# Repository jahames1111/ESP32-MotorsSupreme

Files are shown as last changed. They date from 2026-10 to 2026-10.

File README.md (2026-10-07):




# ESP32-MotorsSupreme

A huge motor driver board based on ESP32 featuring capacitors and motor/servo output pins everywhere.

## Features

- 8 DRV8833 motor drivers for 16 2 directional PWM motor outputs
- 2 PCA9685 chips for servo outputs and one pin of the DRV channels (the other is the ESP pin)
- 16 ESP32-S2 WROVER pins for DRV direction control
- Built for testing nonworking motors and servos



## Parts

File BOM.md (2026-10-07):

# ESP32-Motors Supreme — bill of materials

<!-- Generated by Half Life from project cmuv750pn0ea501smdojupz3y. Edits here are overwritten on the next sync. -->
<!-- Generated: 2026-10-07T14:09:51.534Z -->

> [!NOTE]
> This parts list is mirrored from [Half Life](https://halflife.hackclub.com). Editing it here will not change the platform's copy, and the next sync overwrites this file.

| Week | Tier | Parts funding |
| --- | --- | --- |
| Week 1 | Tier 2 | $65.00 |

| Part | What it's for | Qty | Unit | Total | Vendor |
| --- | --- | --- | --- | --- | --- |
| [JLCPCB Printed Board + Enclosure case](https://cart.jlcpcb.com/shopcart/cartEdit/?id=c26c80bae765480d8adc16bf88983d1a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) | Main PCB + case | 1 | $13.00 | $13.00 | [JLCPCB](https://cart.jlcpcb.com/shopcart/cartEdit/?id=c26c80bae765480d8adc16bf88983d1a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) |
| [LCSC Parts](https://www.lcsc.com/cart) | PCB Assembly | 1 | $45.00 | $45.00 | [LCSC](https://www.lcsc.com/cart) |
| **Parts subtotal** | — | — | — | **$58.00** | — |
| **Tax & shipping** | — | — | — | **$0.00** | — |
| **Total** | — | — | — | **$58.00** | — |

$7.00 left of the tier's funding.

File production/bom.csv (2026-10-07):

Designator | Footprint | Quantity | Value | LCSC Part #
C1 | CP_Radial_D8.0mm_P3.50mm | 1 | 470uf
C10, C12, C13, C14, C15, C16, C17, C18, C19, C3, C4, C5, C6, C7, C8, C9 | 1206 | 16 | 2.2uf
C11 | 1206 | 1 | 0.1uf
C2 | 1206 | 1 | 470uf
D1, D2 | D_SMA | 2 | D_Schottky
J1 | SolderWire-1sqmm_1x01_D1.4mm_OD3.9mm | 1 | BAT-
J10, J11, J12, J13, J14, J15, J16, J17, J18, J3, J4, J5, J6, J7, J8, J9 | PinHeader_1x02_P2.54mm_Vertical | 16 | Conn_01x02_Pin
J19, J20, J21 | PinHeader_1x16_P2.54mm_Vertical | 3 | Conn_01x16_Pin
J2 | SolderWire-1sqmm_1x01_D1.4mm_OD3.9mm | 1 | BAT+
J22 | USB_C_Receptacle_HRO_TYPE-C-31-M-12 | 1 | USB_C_Receptacle_USB2.0_16P
R1, R2 | 1206 | 2 | 4.7k
R3, R4, R5, R6 | 1206 | 4 | 5.1k
SW1, SW2 | SW_PUSH_6mm | 2 | SW_Push
U1 | ESP32-S2-WROVER | 1 | ESP32-S2-WROVER
U10, U11, U12, U13, U6, U7, U8, U9 | HTSSOP-16-1EP_4.4x5mm_P0.65mm_EP3.4x5mm_Mask2.46x2.31mm_ThermalVias | 8 | DRV8833PWP
U2, U5 | TSSOP-28_4.4x9.7mm_P0.65mm | 2 | PCA9685PW
U3 | SOT-23-5 | 1 | MIC5219-3.3YM5

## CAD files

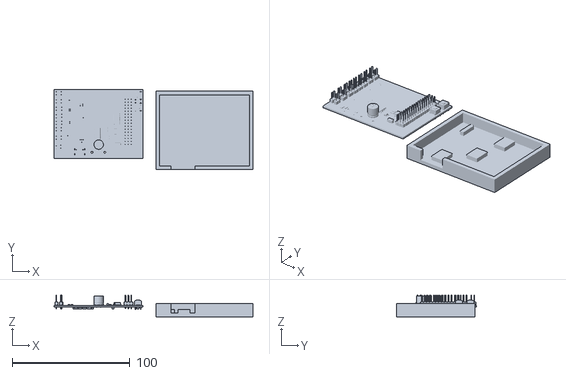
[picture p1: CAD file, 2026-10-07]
board and holder.stl
169.2 x 68.3 x 18.4

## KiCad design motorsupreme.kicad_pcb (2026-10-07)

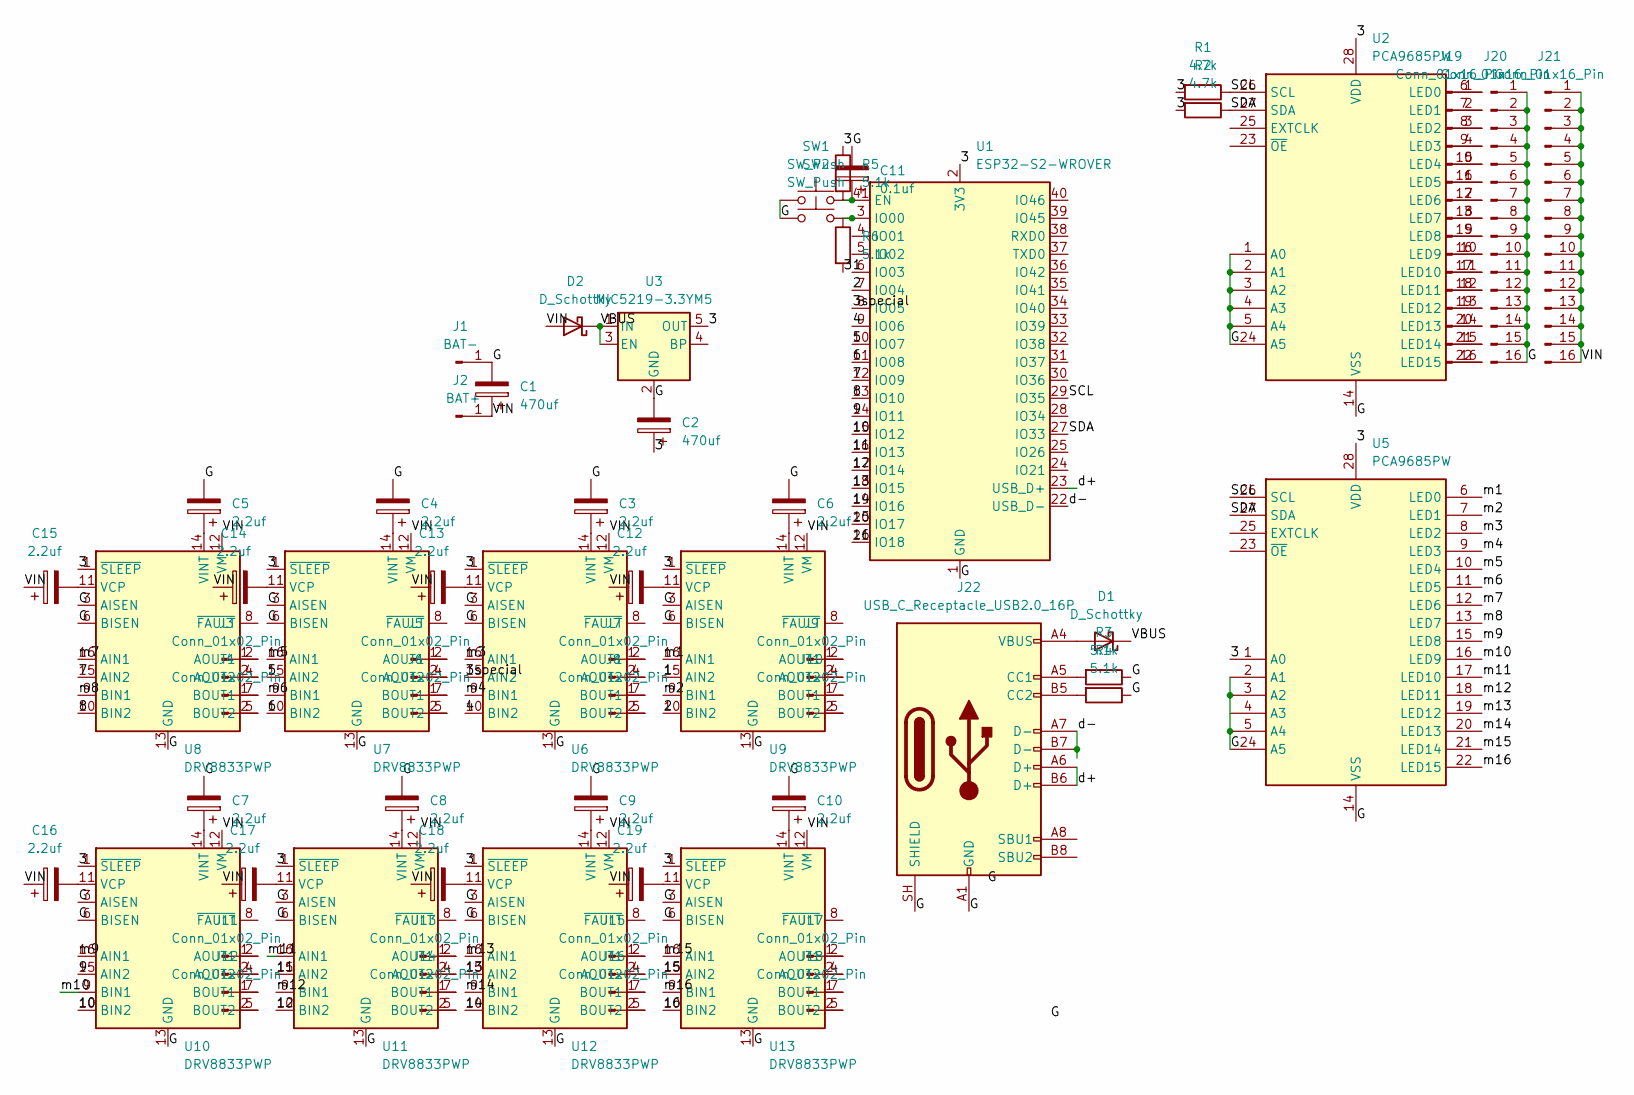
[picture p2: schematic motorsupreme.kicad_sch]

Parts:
C1: 470uf; CP_Radial_D8.0mm_P3.50mm
C2: 470uf; C_1206_3216Metric
C3, C4, C5, C6, C7, C8, C9, C10, C12, C13, C14, C15, C16, C17, C18, C19: 2.2uf; C_1206_3216Metric
C11: 0.1uf; C_1206_3216Metric
D1, D2: D_Schottky; D_SMA
J1: BAT-; SolderWire-1sqmm_1x01_D1.4mm_OD3.9mm
J2: BAT+; SolderWire-1sqmm_1x01_D1.4mm_OD3.9mm
J3, J4, J5, J6, J7, J8, J9, J10, J11, J12, J13, J14, J15, J16, J17, J18: Conn_01x02_Pin; PinHeader_1x02_P2.54mm_Vertical
J19, J20, J21: Conn_01x16_Pin; PinHeader_1x16_P2.54mm_Vertical
J22: USB_C_Receptacle_USB2.0_16P; USB_C_Receptacle_HRO_TYPE-C-31-M-12
R1, R2: 4.7k; R_1206_3216Metric
R3, R4, R5, R6: 5.1k; R_1206_3216Metric
SW1, SW2: SW_Push; SW_PUSH_6mm
U1: ESP32-S2-WROVER
U2, U5: PCA9685PW; TSSOP-28_4.4x9.7mm_P0.65mm
U3: MIC5219-3.3YM5; SOT-23-5
U6, U7, U8, U9, U10, U11, U12, U13: DRV8833PWP; HTSSOP-16-1EP_4.4x5mm_P0.65mm_EP3.4x5mm_Mask2.46x2.31mm_The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

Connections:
/1: U1.6 (IO03), U9.15 (AIN2)
/2: U1.7 (IO04), U9.10 (BIN2)
/3: C2.1, R1.2, R2.2, R5.1, R6.2, U1.2 (3V3), U2.28 (VDD), U3.5 (OUT), U5.1 (A0), U5.28 (VDD), U6.1 (~SLEEP), U7.1 (~SLEEP), U8.1 (~SLEEP), U9.1 (~SLEEP), U10.1 (~SLEEP), U11.1 (~SLEEP), U12.1 (~SLEEP), U13.1 (~SLEEP)
/3special: U1.8 (IO05), U6.15 (AIN2)
/4: U1.9 (IO06), U6.10 (BIN2)
/5: U1.10 (IO07), U7.15 (AIN2)
/6: U1.11 (IO08), U7.10 (BIN2)
/7: U1.12 (IO09), U8.15 (AIN2)
/8: U1.13 (IO10), U8.10 (BIN2)
/9: U1.14 (IO11), U10.15 (AIN2)
/10: U1.15 (IO12), U10.10 (BIN2)
/11: U1.16 (IO13), U11.15 (AIN2)
/12: U1.17 (IO14), U11.10 (BIN2)
/13: U1.18 (IO15), U12.15 (AIN2)
/14: U1.19 (IO16), U12.10 (BIN2)
/15: U1.20 (IO17), U13.15 (AIN2)
/16: U1.21 (IO18), U13.10 (BIN2)
/G: C1.2, C2.2, C3.2, C4.2, C5.2, C6.2, C7.2, C8.2, C9.2, C10.2, C11.2, J1.1 (Pin_1_1), J20.1, J20.2, J20.3, J20.4, J20.5, J20.6, J20.7, J20.8, J20.9, J20.10, J20.11, J20.12, J20.13, J20.14, J20.15, J20.16, J22.A1 (GND), J22.A12 (GND), J22.B1 (GND), J22.B12 (GND), J22.SH (SHIELD), R3.1, R4.1, SW1.1, SW2.1, U1.1 (GND), U1.26 (GND), U1.42 (GND), U1.43 (GND), U2.1 (A0), U2.2 (A1), U2.3 (A2), U2.4 (A3), U2.5 (A4), U2.14 (VSS), U2.24 (A5), U3.2 (GND), U5.2 (A1), U5.3 (A2), U5.5 (A4), U5.14 (VSS), U5.24 (A5), U6.3 (AISEN), U6.6 (BISEN), U6.13 (GND), U6.17 (GND), U7.3 (AISEN), U7.6 (BISEN), U7.13 (GND), U7.17 (GND), U8.3 (AISEN), U8.6 (BISEN), U8.13 (GND), U8.17 (GND), U9.3 (AISEN), U9.6 (BISEN), U9.13 (GND), U9.17 (GND), U10.3 (AISEN), U10.6 (BISEN), U10.13 (GND), U10.17 (GND), U11.3 (AISEN), U11.6 (BISEN), U11.13 (GND), U11.17 (GND), U12.3 (AISEN), U12.6 (BISEN), U12.13 (GND), U12.17 (GND), U13.3 (AISEN), U13.6 (BISEN), U13.13 (GND), U13.17 (GND)
/SCL: R1.1, U1.29 (IO35), U2.26 (SCL), U5.26 (SCL)
/SDA: R2.1, U1.27 (IO33), U2.27 (SDA), U5.27 (SDA)
/VBUS: D1.1 (K), D2.1 (K), U3.1 (IN), U3.3 (EN)
/VIN: C1.1, C12.1, C13.1, C14.1, C15.1, C16.1, C17.1, C18.1, C19.1, D2.2 (A), J2.1 (Pin_1_1), J21.1, J21.2, J21.3, J21.4, J21.5, J21.6, J21.7, J21.8, J21.9, J21.10, J21.11, J21.12, J21.13, J21.14, J21.15, J21.16, U6.12 (VM), U7.12 (VM), U8.12 (VM), U9.12 (VM), U10.12 (VM), U11.12 (VM), U12.12 (VM), U13.12 (VM)
/d+: J22.A6 (D+), J22.B6 (D+), U1.23 (USB_D+)
/d-: J22.A7 (D-), J22.B7 (D-), U1.22 (USB_D-)
/m1: U5.6 (LED0), U9.16 (AIN1)
/m2: U5.7 (LED1), U9.9 (BIN1)
/m3: U5.8 (LED2), U6.16 (AIN1)
/m4: U5.9 (LED3), U6.9 (BIN1)
/m5: U5.10 (LED4), U7.16 (AIN1)
/m6: U5.11 (LED5), U7.9 (BIN1)
/m7: U5.12 (LED6), U8.16 (AIN1)
/m8: U5.13 (LED7), U8.9 (BIN1)
/m9: U5.15 (LED8), U10.16 (AIN1)
/m10: U5.16 (LED9), U10.9 (BIN1)
/m11: U5.17 (LED10), U11.16 (AIN1)
/m12: U5.18 (LED11), U11.9 (BIN1)
/m13: U5.19 (LED12), U12.16 (AIN1)
/m14: U5.20 (LED13), U12.9 (BIN1)
/m15: U5.21 (LED14), U13.16 (AIN1)
/m16: U5.22 (LED15), U13.9 (BIN1)
unnamed: D1.2 (A), J22.A4 (VBUS), J22.A9 (VBUS), J22.B4 (VBUS), J22.B9 (VBUS)
unnamed: J3.1, U8.2 (AOUT1)
unnamed: J3.2, U8.4 (AOUT2)
unnamed: J4.1, U8.7 (BOUT1)
unnamed: J4.2, U8.5 (BOUT2)
unnamed: J5.1, U7.2 (AOUT1)
unnamed: J5.2, U7.4 (AOUT2)
unnamed: J6.1, U7.7 (BOUT1)
unnamed: J6.2, U7.5 (BOUT2)
unnamed: J7.1, U6.2 (AOUT1)
unnamed: J7.2, U6.4 (AOUT2)
unnamed: J8.1, U6.7 (BOUT1)
unnamed: J8.2, U6.5 (BOUT2)
unnamed: J9.1, U9.2 (AOUT1)
unnamed: J9.2, U9.4 (AOUT2)
unnamed: J10.1, U9.7 (BOUT1)
unnamed: J10.2, U9.5 (BOUT2)
unnamed: J11.1, U10.2 (AOUT1)
unnamed: J11.2, U10.4 (AOUT2)
unnamed: J12.1, U10.7 (BOUT1)
unnamed: J12.2, U10.5 (BOUT2)
unnamed: J13.1, U11.2 (AOUT1)
unnamed: J13.2, U11.4 (AOUT2)
unnamed: J14.1, U11.7 (BOUT1)
unnamed: J14.2, U11.5 (BOUT2)
unnamed: J15.1, U12.2 (AOUT1)
unnamed: J15.2, U12.4 (AOUT2)
unnamed: J16.1, U12.7 (BOUT1)
unnamed: J16.2, U12.5 (BOUT2)
unnamed: J17.1, U13.2 (AOUT1)
unnamed: J17.2, U13.4 (AOUT2)
unnamed: J18.1, U13.7 (BOUT1)
unnamed: J18.2, U13.5 (BOUT2)
unnamed: J19.1, U2.6 (LED0)
unnamed: J19.2, U2.7 (LED1)
unnamed: J19.3, U2.8 (LED2)
unnamed: J19.4, U2.9 (LED3)
unnamed: J19.5, U2.10 (LED4)
unnamed: J19.6, U2.11 (LED5)
unnamed: J19.7, U2.12 (LED6)
unnamed: J19.8, U2.13 (LED7)
unnamed: J19.9, U2.15 (LED8)
unnamed: J19.10, U2.16 (LED9)
unnamed: J19.11, U2.17 (LED10)
unnamed: J19.12, U2.18 (LED11)
unnamed: J19.13, U2.19 (LED12)
unnamed: J19.14, U2.20 (LED13)
unnamed: J19.15, U2.21 (LED14)
unnamed: J19.16, U2.22 (LED15)
unnamed: J22.A5 (CC1), R3.2
unnamed: J22.B5 (CC2), R4.2
unnamed: C11.1, R5.2, SW1.2, U1.41 (EN)
unnamed: R6.1, SW2.2, U1.3 (IO00)
unnamed: C13.2, U6.11 (VCP)
unnamed: C3.1, U6.14 (VINT)
unnamed: C14.2, U7.11 (VCP)
unnamed: C4.1, U7.14 (VINT)
unnamed: C15.2, U8.11 (VCP)
unnamed: C5.1, U8.14 (VINT)
unnamed: C12.2, U9.11 (VCP)
unnamed: C6.1, U9.14 (VINT)
unnamed: C16.2, U10.11 (VCP)
unnamed: C7.1, U10.14 (VINT)
unnamed: C17.2, U11.11 (VCP)
unnamed: C8.1, U11.14 (VINT)
unnamed: C18.2, U12.11 (VCP)
unnamed: C9.1, U12.14 (VINT)
unnamed: C19.2, U13.11 (VCP)
unnamed: C10.1, U13.14 (VINT)

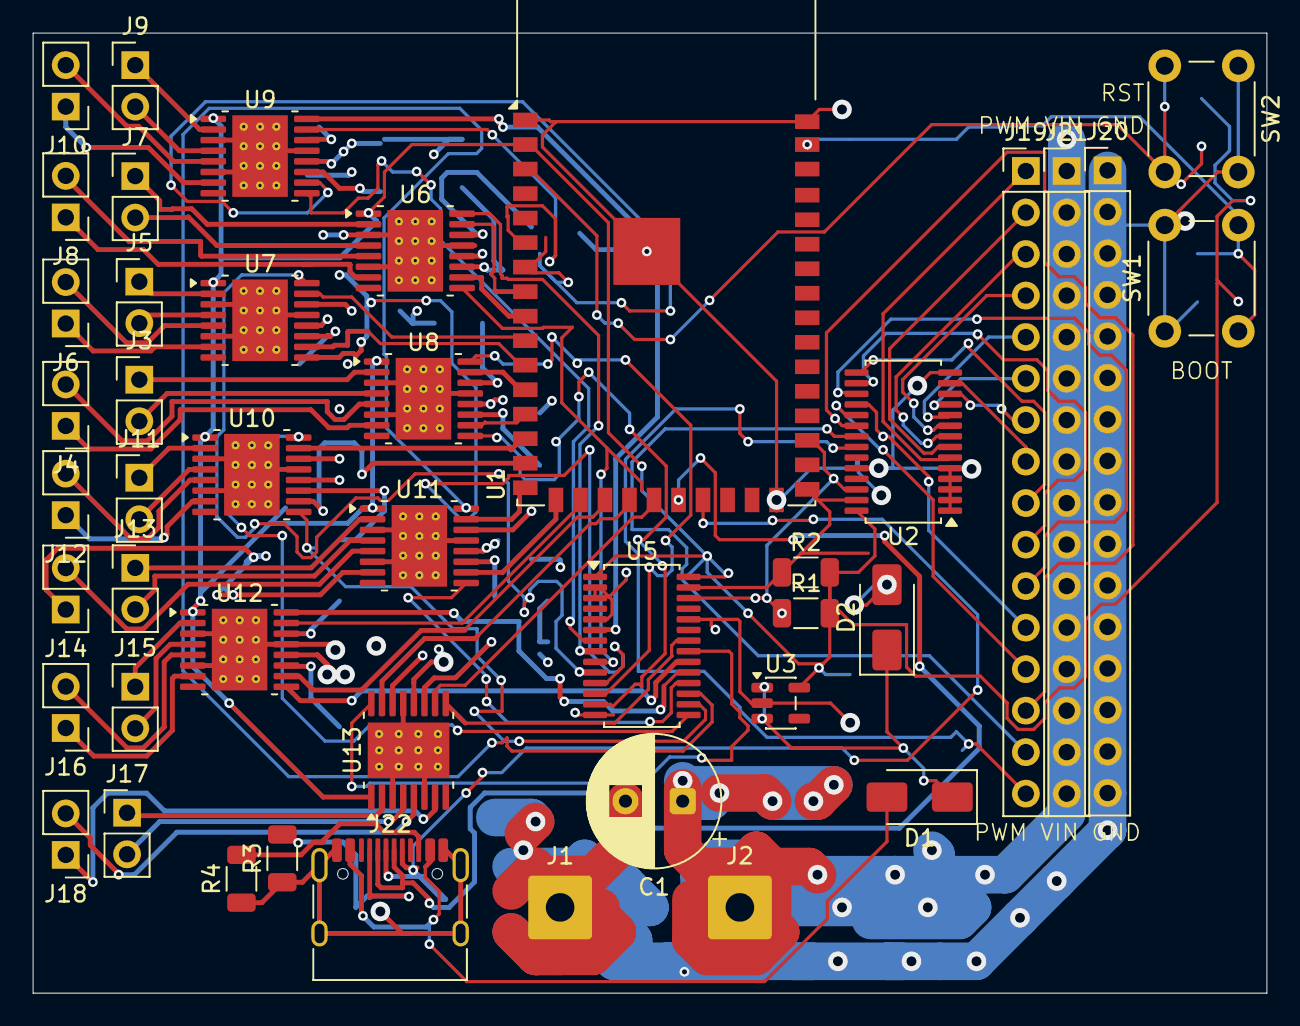
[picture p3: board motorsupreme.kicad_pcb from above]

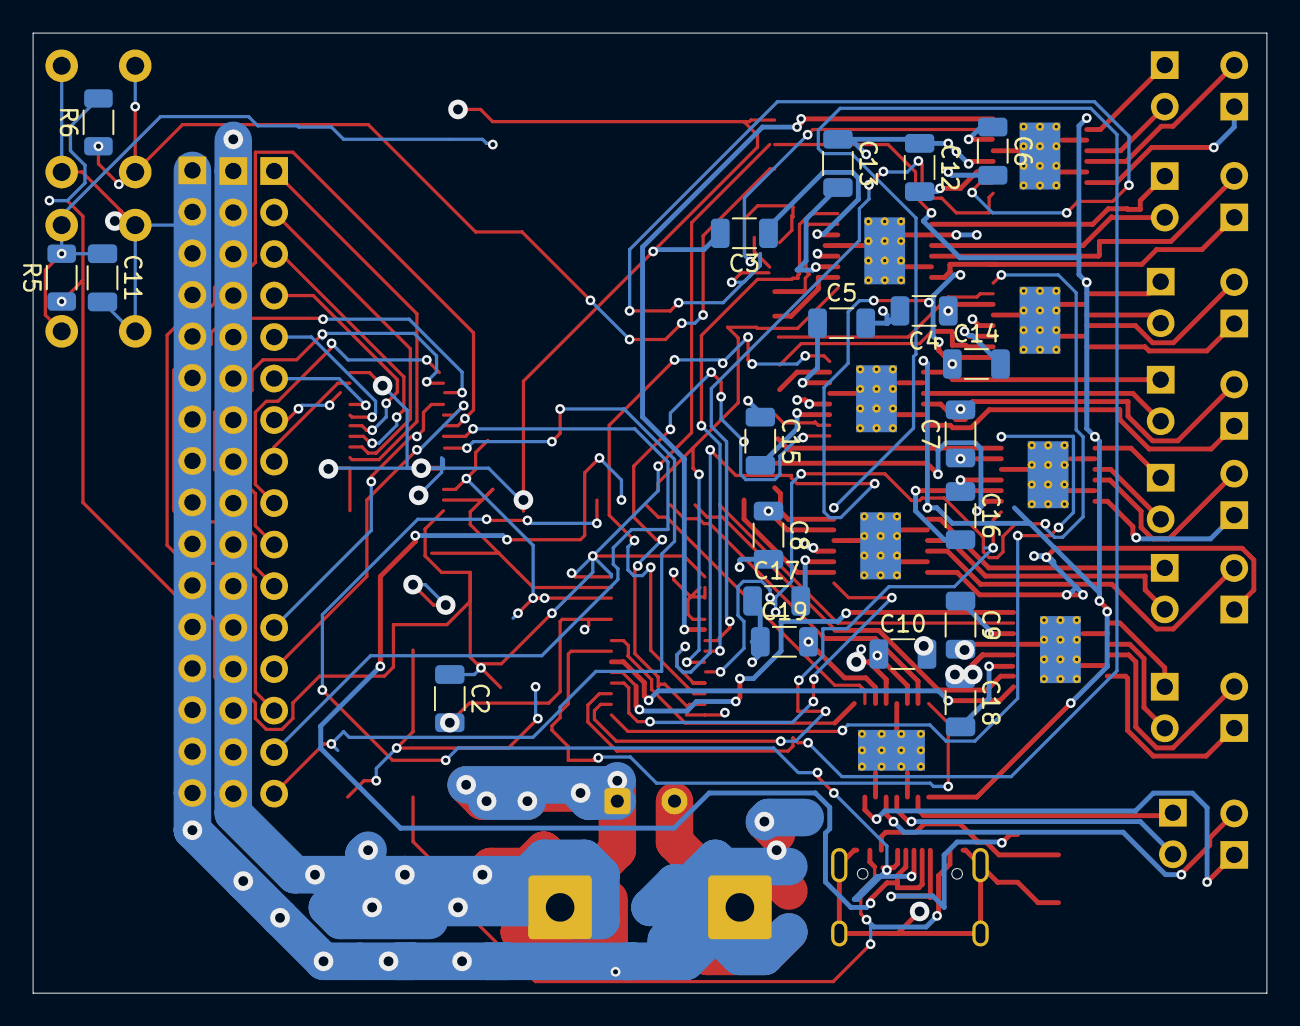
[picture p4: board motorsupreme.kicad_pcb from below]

Board: 4 copper layers, 75.5 x 58.8 mm, 63 parts (20 on the bottom side), 109 nets.

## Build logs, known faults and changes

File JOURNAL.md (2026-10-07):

# ESP32-Motors Supreme — devlog

<!-- Generated by Half Life from project cmuv750pn0ea501smdojupz3y. Edits here are overwritten on the next sync. -->
<!-- Generated: 2026-10-07T17:11:28.992Z -->

> [!NOTE]
> This devlog is mirrored from [Half Life](https://halflife.hackclub.com). Editing it here will not change the platform's copy, and the next sync overwrites this file.

> A huge motor driver board based on ESP32 featuring capacitors and motor/servo output pins everywhere.

| Week | Tier | Hours logged | Entries |
| --- | --- | --- | --- |
| Week 1 | Tier 2 | 23.5h | 6 |

## Contents

1. [2026-10-06 — ](#2026-10-06-screenshot-2026-10-06-063157httpshalflifehackclub)
2. [2026-10-06 — - Finished the PCB design, had to redesign the entire PCB to adjust for the space constraints, so I added 2 new layers: GND and VIN](#2026-10-06---finished-the-pcb-design-had-to-redesign-the-ent)
3. [2026-10-07 — Digital testing using Wokwi, I wrote INO code and worked for quite a bit to arrange the serial commands to the servos. I kept having indexing problems, but that was because I apparently mismatched the](#2026-10-07-digital-testing-using-wokwi-i-wrote-ino-code-and-)
4. [2026-10-07 — Shopping!](#2026-10-07-shopping)
5. [2026-10-07 — ](#2026-10-07-screenshot-2026-10-07-092706httpshalflifehackclub)
6. [2026-10-07 — Got bored and kept working on the project.](#2026-10-07-got-bored-and-kept-working-on-the-project)

## Design

### 2026-10-06 — 

**4h**









Worked on designing the initial PCB. Added all the DRVs, PCBs, and wired up the literal dozens of required capacitors. Most of it is done, but I still have to finish routing and placing all the tiny components.

### 2026-10-06 — - Finished the PCB design, had to redesign the entire PCB to adjust for the space constraints, so I added 2 new layers: GND and VIN

**6h**

- Finished the PCB design, had to redesign the entire PCB to adjust for the space constraints, so I added 2 new layers: GND and VIN
-Added boot/reset buttons and a USB-C 2.0 programming port
-Added extra vias everywhere so as to not short out the power traces when running high-current motors
-Ran DRC multiple times to get rid of loose, unconnected traces (all meaningful errors and warnings gone; what's left is just footprint overlap stuff with the servo pins connector, which is not a problem.)












### 2026-10-07 — Digital testing using Wokwi, I wrote INO code and worked for quite a bit to arrange the serial commands to the servos. I kept having indexing problems, but that was because I apparently mismatched the

**5h**

Digital testing using Wokwi, I wrote INO code and worked for quite a bit to arrange the serial commands to the servos. I kept having indexing problems, but that was because I apparently mismatched the digital pins to the numbers in the code. Finally finished code with serial commands to adjust servo angles and motor speeds.













### 2026-10-07 — Shopping!

**2h**

Shopping!
I spent this time going to JLCPCB and LCSC and configuring the PCB. I made sure to select Lead-Free HASL because I had a coupon for $30 off a 4-layer board.


Then, I went to LCSC and uploaded the BOM and spent quite some time trying to match the right components for the easy-to-solder components that I picked.



### 2026-10-07 — 

**4h**





Created a 3d model representation of the board, then created a cover for it. I had to approximate the position of the components because the export-as-STL option didn't include the components in KiCAD.
Might add it to the cart and get it printed.





### 2026-10-07 — Got bored and kept working on the project.

**2.5h**

Got bored and kept working on the project.
In the past, I have had problems with I2C recognition when using the PCA9865 under load, so I added better pull-up resistors for the I2C lines and wrote an I2C scanner and config sketch for when I assemble the project.







Code:
#include

#define SDA_PIN 33
#define SCL_PIN 35

void checkDevice(uint8_t addr) {
  Wire.beginTransmission(addr);
  uint8_t error = Wire.endTransmission();

  if (error == 0) {
    Serial.print("0x");
    if (addr < 16) Serial.print("0");
    Serial.print(addr, HEX);
    Serial.print(": ");

    if (addr == 0x40) Serial.println("PCA9685 PWM Controller #1");
    else if (addr == 0x41) Serial.println("PCA9685 PWM Controller #2");
    else if (addr == 0x70) Serial.println("PCA9685 All-Call Address");
    else Serial.println("Unknown Device");
  }
}

void verifyRegisters(uint8_t addr) {
  Wire.beginTransmission(addr);
  Wire.write(0x00);
  if (Wire.endTransmission() != 0) return;

  Wire.requestFrom(addr, (uint8_t)1);
  if (Wire.available()) {
    uint8_t mode1 = Wire.read();
    Serial.print(" -> Mode1 Register (0x00): 0x");
    if (mode1 < 16) Serial.print("0");
    Serial.println(mode1, HEX);
  }
}

void setup() {
  Serial.begin(115200);
  while (!Serial);

  Wire.begin(SDA_PIN, SCL_PIN, 100000);
  Serial.println("Scanning 100kHz...");
  for (uint8_t addr = 1; addr < 127; addr++) {
    checkDevice(addr);
  }

  Wire.setClock(400000);
  Serial.println("\nScanning 400kHz...");
  for (uint8_t addr = 1; addr < 127; addr++) {
    checkDevice(addr);
  }

  Serial.println("\nReading Active Configurations:");
  verifyRegisters(0x40);
  verifyRegisters(0x41);
}

void loop() {
}

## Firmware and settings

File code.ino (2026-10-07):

#include <Wire.h>

#define PCA1_ADDR 0x40
#define PCA2_ADDR 0x41

#define SDA_PIN 33
#define SCL_PIN 35

void writeReg(uint8_t devAddr, uint8_t regAddr, uint8_t value) {
  Wire.beginTransmission(devAddr);
  Wire.write(regAddr);
  Wire.write(value);
  Wire.endTransmission();
}

void initPCA9685(uint8_t devAddr) {
  writeReg(devAddr, 0x00, 0x10);
  writeReg(devAddr, 0xFE, 0x79);
  writeReg(devAddr, 0x00, 0x00);
  delay(5);
  writeReg(devAddr, 0x00, 0xA1);
}

void setPWM(uint8_t devAddr, uint8_t channel, uint16_t onTime, uint16_t offTime) {
  Wire.beginTransmission(devAddr);
  Wire.write(0x06 + (channel * 4));
  Wire.write((uint8_t)(onTime & 0xFF));
  Wire.write((uint8_t)(onTime >> 8));
  Wire.write((uint8_t)(offTime & 0xFF));
  Wire.write((uint8_t)(offTime >> 8));
  Wire.endTransmission();
}

void driveMotor(uint8_t motorIndex, int16_t speed) {
  uint8_t devAddr = (motorIndex < 8) ? PCA1_ADDR : PCA2_ADDR;
  uint8_t baseChan = (motorIndex % 8) * 2;
  
  if (speed > 4095) speed = 4095;
  if (speed < -4095) speed = -4095;

  if (speed >= 0) {
    setPWM(devAddr, baseChan, 0, speed);
    setPWM(devAddr, baseChan + 1, 4096, 0);
  } else {
    setPWM(devAddr, baseChan, 4096, 0);
    setPWM(devAddr, baseChan + 1, 0, -speed);
  }
}

void setServoAngle(uint8_t pinIndex, uint16_t angle) {
  uint8_t devAddr = (pinIndex < 16) ? PCA1_ADDR : PCA2_ADDR;
  uint8_t channel = pinIndex % 16;

  if (angle > 180) angle = 180;

  uint16_t offTime = 150 + ((angle * 450) / 180);
  setPWM(devAddr, channel, 0, offTime);
}

void processCommand(String input) {
  input.trim();
  if (input.length() == 0) return;

  char cmdType = input.charAt(0);
  int firstSpace = input.indexOf(' ');
  if (firstSpace == -1) return;

  int idx = input.substring(1, firstSpace).toInt();
  int val = input.substring(firstSpace + 1).toInt();

  if (cmdType == 'm' || cmdType == 'M') {
    driveMotor(idx, val);
    Serial.print("Motor ");
    Serial.print(idx);
    Serial.print(" speed set to: ");
    Serial.println(val);
  } 
  else if (cmdType == 's' || cmdType == 'S') {
    setServoAngle(idx, val);
    Serial.print("Servo Pin ");
    Serial.print(idx);
    Serial.print(" angle set to: ");
    Serial.println(val);
  }
}

void setup() {
  Serial.begin(115200);
  delay(1000);
  Wire.begin(SDA_PIN, SCL_PIN, 400000);
  initPCA9685(PCA1_ADDR);
  initPCA9685(PCA2_ADDR);
  Serial.println("System Ready. Commands: 'm[index] [speed]' or 's[pin] [angle]'");
}

void loop() {
  if (Serial.available() > 0) {
    String inputString = Serial.readStringUntil('\n');
    processCommand(inputString);
  }
}

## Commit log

2026-10-06 Update README with hardware feature list based on provided board details
2026-10-06 Add images to README for ESP32-MotorsSupreme
    Added images to enhance the visual representation of the ESP32-MotorsSupreme project.
2026-10-07 Add motor and servo control functions
2026-10-07 Sync ESP32-Motors Supreme from Half Life
2026-10-07 Update motor driver features in README
    Clarified motor output descriptions for better understanding.
2026-10-07 Add I2C scanner for PCA9685 devices
    This sketch scans I2C addresses and verifies registers for PCA9685 PWM controllers.
2026-10-17 Add LCSC part numbers to BOM
    Updated the BOM with LCSC part numbers for components.
2026-10-17 Add BOM section to README
    Added a Bill of Materials (BOM) section with component details and costs.
2026-10-17 Revise BOM with JLCPCB PCB details
    Updated BOM to include PCB from JLCPCB.
2026-10-17 Revise BOM format in README.md
    Updated the Bill of Materials (BOM) format to a table for better readability and included the total cost.
2026-10-17 Revise BOM with product links and formatting
    Updated the Bill of Materials (BOM) section to include product links and formatted the table for clarity.
2026-10-17 Rename board and holder.stl to 3d/board and holder.stl
2026-10-17 Rename BOM (4).csv to BOM.csv
2026-10-17 Rename BOM (5).csv to BOM.csv
2026-10-17 Rename board and holder.zip to 3d/board and holder.zip
2026-10-17 Add new 3D model files for board and holder
2026-10-17 Revise BOM with detailed components and links
    Updated BOM section to include detailed component information and sourcing links.
2026-10-17 Revise BOM with updated component information
    Updated component details including designators, footprints, and sourcing links.
2026-10-17 Revise BOM with updated part numbers and descriptions
    Updated LCSC part numbers and descriptions for components in the BOM section.
2026-10-18 Update BOM.csv with pricing information
    Added unit price and extended price columns to BOM.
2026-10-18 Revise BOM with detailed component names
    Updated component names and descriptions in BOM.
2026-10-22 Add assembly instructions to README
    Added assembly instructions for the 3D printed frame and code upload process.
2026-10-22 Enhance README with wiring schematic images
    Added detailed wiring schematic images for better understanding.
2026-10-22 Update wiring schematic images in README
    Replaced larger schematic screenshots with smaller versions for better readability.
2026-10-22 Enhance wiring section with more schematic images
    Added additional detailed schematic screenshots to the wiring section.
2026-10-22 Update wiring screenshots in README
    Removed old wiring screenshots and added new detailed images.
2026-10-22 Replace assembly image in README
    Updated the image in the Assembly section of the README.
2026-10-22 Update README to remove duplicate image and add wiring section
    Removed duplicate image in the README and added a new wiring section with a detailed schematic screenshot.
2026-10-22 Update README with BOM section for components
    Added BOM section with details for ESP32-S2-WROVER Module.
